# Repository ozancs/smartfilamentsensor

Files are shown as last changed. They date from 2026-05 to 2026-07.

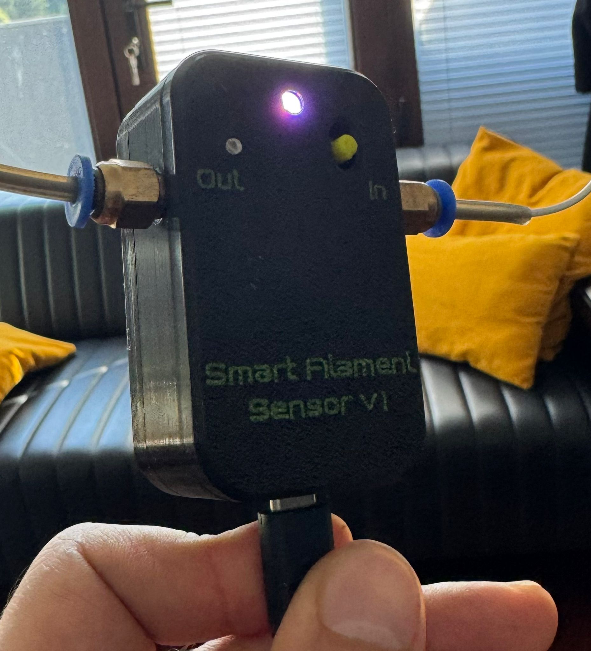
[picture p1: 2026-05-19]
photos/final.jpeg

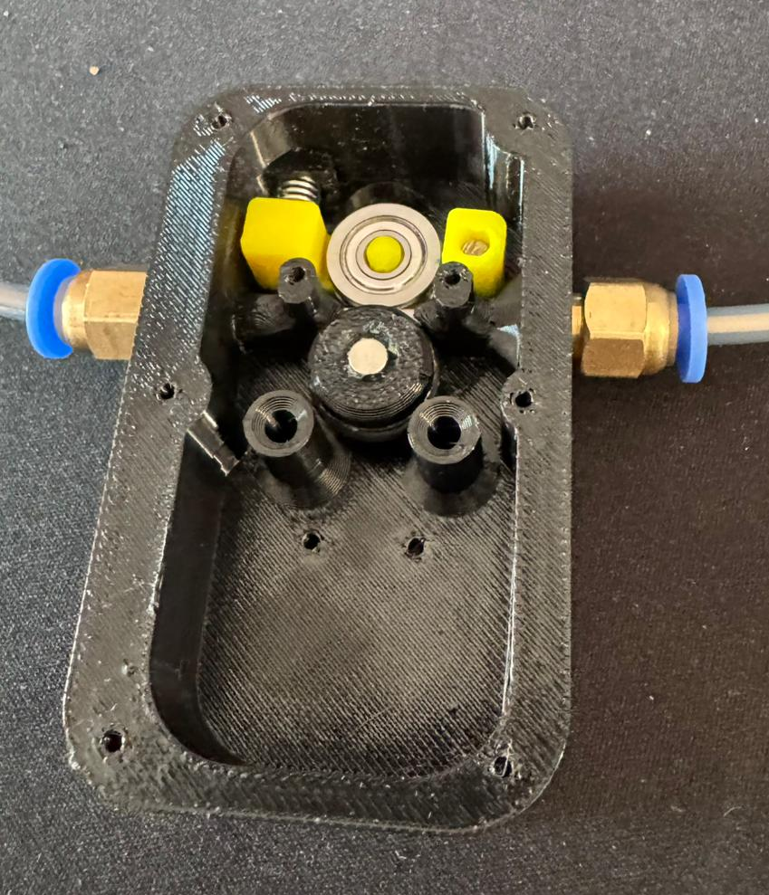
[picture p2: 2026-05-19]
photos/inside.png

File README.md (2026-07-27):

# Smart Filament Sensor

High-precision filament motion sensor for 3D printers. Uses an **ESP32-C3** and **AS5600** magnetic encoder to detect clogs, runouts, and slippage in real-time with native **Klipper** integration.

> **Build video coming soon** — in the meantime, follow the **[Installation Guide](INSTALLATION_GUIDE.md)** and use the [interactive CAD model](https://a360.co/4fwGLLL) for reference.

---

## Features

- **Sub-mm accuracy** — AS5600 contactless encoder (4096 steps/rev), no drift
- **Drag-immune clog detection** — averages over 200mm of *extrusion distance*, not seconds, so bowden drag cannot fake a clog (see [How It Works](#how-it-works))
- **Self-checking calibration** — measures encoder-vs-extruder gain live; if it drifts, the module warns instead of pausing your print for a calibration fault
- **Auto-detect serial port** — no need to manually set `/dev/ttyACM0`, finds ESP32 automatically
- **Underextrusion tracking** — rolling average exposed to Moonraker/Mainsail/Fluidd dashboards
- **Magnet health monitoring** — uses the AS5600's own MH/ML status bits, warns on weak, **too strong**, or missing magnet
- **Sensor watchdog** — detects USB disconnection, warns user, blocks commands when offline
- **Auto-reconnect** — recovers from USB dropouts on its own, no `FIRMWARE_RESTART` needed
- **No false pauses on dropout** — a disconnect means "no data", never "no filament"; detection state resyncs instead of tripping a clog
- **Homing awareness** — pauses detection during homing to prevent false triggers
- **One-command calibration** — `SFS_AUTO_CALIBRATE LENGTH=100`, heats, extrudes, saves
- **Built-in diagnostics** — `SFS_DIAG` dumps every AS5600 register for troubleshooting
- **Status LED** — WS2812B breathing/pulse animations (idle, moving, calibrating)
- **Windows console app** — portable .exe for calibration, live measurement, settings, firmware flashing

---

## Bill of Materials

| Component | Qty | Notes |
|---|---|---|
| ESP32-C3 Super Mini | 1 | Main MCU |
| AS5600 Encoder Module | 1 | With diametrical magnet |
| WS2812B NeoPixel 5050 | 1 | Status LED |
| Grooved Bearing (U604ZZ) | 2 | OD 13mm, ID 4mm |
| Dowel Pin 3mm x 15mm | 1 | Bearing axle |
| O-Ring (~11mm OD) | 1 | Filament grip |
| PC4-M6 Fitting | 2 | Bowden tube entry/exit |
| Compression Spring | 1 | Pen-style, cut to length |
| M3 Screw (M3x8-M3x10) | 1 | |
| M2 Self-Tapping Screw | 2 | AS5600 + ESP32 mount |

Full BOM: [`3d_print_files_and_bom/bom.html`](3d_print_files_and_bom/bom.html)

---

## 3D Printed Parts

Files in [`3d_print_files_and_bom/`](3d_print_files_and_bom/) (print-ready 3MF):

- `SmartFilament_Body_w_Text.3mf` / `SmartFilament_Body_w-out_Text.3mf`
- `BackCover.3mf` / `MagnetHolder.3mf` / `Spring_Arm.3mf`

**[Interactive CAD Model (Fusion 360)](https://a360.co/3QY3KFT)**

---

## Firmware

### Quick Flash (Windows)
1. Download `Smart Filament Sensor Console v2.1.exe`
2. Connect ESP32 via USB → open app → **Firmware** tab → **Flash**

### Build from Source (Arduino IDE)
1. Board: **ESP32C3 Dev Module** (Arduino ESP32 core)
2. Libraries: `AS5600`, `FastLED`
3. Tools → **USB CDC On Boot: Enabled**
4. Open `smart_filament_sensor.ino` → Upload

---

## Klipper Integration

ESP32 only measures filament movement. All clog detection logic runs inside Klipper.

### Setup (with auto-update)

```bash
cd ~
git clone https://github.com/ozancs/smartfilamentsensor.git
~/smartfilamentsensor/install.sh
```

Add to `moonraker.conf` for automatic updates:
```ini
[update_manager smart_filament_sensor]
type: git_repo
path: ~/smartfilamentsensor
origin: https://github.com/ozancs/smartfilamentsensor.git
install_script: install.sh
primary_branch: main
managed_services: klipper
```

**Manual install:** Upload `smart_filament_sensor.py` via Mainsail/Fluidd, then SSH and
`mv ~/printer_data/config/smart_filament_sensor.py ~/klipper/klippy/extras/`

Use `mv`, not `cp` — a leftover copy in the config folder shows up in the
Mainsail/Fluidd file list as if it were a config file, and editing that copy
silently does nothing because Klipper loads the one in `klippy/extras/`.

### printer.cfg

```ini
[smart_filament_sensor sfs]
serial: auto                      # auto-detects ESP32 (or use /dev/serial/by-id/...)
baud: 115200
detection_length: 7.0             # mm of extrusion between each encoder read
detection_window: 200.0           # mm of extrusion averaged per clog decision
underextrusion_max_rate: 0.5      # 0.0-1.0, trip if actual < 50% of expected
min_window_samples: 8             # reads required before any decision is made
encoder_scale: 1.0                # multiplies encoder mm (steady bias correction)
gain_tolerance: 0.25              # |gain-1| above this disarms detection
pause_on_runout: True
runout_gcode: PAUSE
health_check_interval: 30.0       # seconds between health checks
```

**A fixed `serial:` path is strongly recommended over `auto`.** With `auto`,
port probing writes `PING` to candidate ports; if one of them is a Klipper MCU
this can crash the printer. Find yours with `ls /dev/serial/by-id/`.

<details>
<summary><b>Upgrading from v2.x — what changed</b></summary>

`underextrusion_period` is gone. It used to set the averaging window in
*seconds*; the window is now set in *millimetres of extrusion* via
`detection_window`. Old configs still load (the value is reused as a
sample-staleness timeout), but you should replace it.

If you previously loosened `underextrusion_max_rate` to stop false pauses,
put it back to `0.5` — the distance window removes the reason you raised it.
</details>

### GCode Commands

**Detection:**
| Command | Description |
|---|---|
| `SFS_STATUS` | Sensor state, magnet health, encoder gain, window fill, armed/not |
| `SFS_ENABLE` / `SFS_DISABLE` | Toggle clog detection |
| `SFS_RESET` | Re-sync position, restart gain measurement |
| `SFS_DIAG` | Dump firmware version, calibration factor + all AS5600 registers (needs firmware >= 2.4.0) |
| `SFS_SUSPEND` / `SFS_RESUME` | Silence the module during probing (nestable) |

**Calibration:**
| Command | Description |
|---|---|
| `SFS_AUTO_CALIBRATE TEMP=240 LENGTH=100` | One-command: heat, extrude, save |
| `SFS_CALIBRATE LENGTH=100` | Manual calibration start |
| `SFS_CALIBRATE_APPLY` | Save calibration immediately |
| `SFS_CALIBRATE_STOP` | Cancel calibration |

**ESP32 Settings:**
| Command | Description |
|---|---|
| `SFS_SET SENS=5 NOISE=3` | Sensitivity + noise filter |
| `SFS_SET BRIGHT=80` | LED brightness (1-255) |
| `SFS_SET DIR=-1` | Reverse encoder direction |
| `SFS_SET CAL=12.5` | Manual calibration factor (deg/mm) |

### Calibration

```gcode
; Automatic (recommended) — heats, extrudes, saves:
SFS_AUTO_CALIBRATE TEMP=240 LENGTH=100 SPEED=100

; Manual — you control the extrusion:
SFS_CALIBRATE LENGTH=100
G1 E100 F100
SFS_CALIBRATE_APPLY
```

Use **100mm, not 50mm**. The wheel travels ~30mm of filament per revolution,
so a short extrude samples only part of one turn and any per-revolution error
folds straight into the result.

### Verifying calibration

Calibrating is not the same as being calibrated. Run a normal print, then:

```gcode
SFS_STATUS
```

Look at **`encoder_gain`** — the long-run ratio of measured to commanded
extrusion. It should settle near `1.000`.

| `encoder_gain` | Meaning |
|---|---|
| ~1.00 | Correct. Clog detection is armed. |
| < 0.90 | The wheel is turning less than the filament moves. Detection **disarms itself** and warns. |
| > 1.10 | Reading too much movement — check magnet placement. |
| negative | The encoder counts backwards. Flip it with `SFS_SET DIR=-1` (or `DIR=1`), then `SFS_RESET`. Usually means the magnet was reinstalled the other way up. |

A low gain that *survives recalibration* is mechanical, not a config problem:
the O-ring is slipping on the filament. Check spring pressure, O-ring
condition, and that the filament path through the sensor is straight.

Full guide: [`klipper_guide/KLIPPER_GUIDE.txt`](klipper_guide/KLIPPER_GUIDE.txt)

---

## Console App (Windows)

Portable `.exe` — no installation required.

- **Dashboard** — calibration wizard, live mm readout, sensor settings
- **Serial Monitor** — raw terminal with quick-action buttons for all commands
- **Firmware** — one-click ESP32 flash with bundled esptool
- **Klipper Guide** — config snippets and full Python module

---

## How It Works

```
Every 7mm of extrusion, Klipper asks the ESP32 how much filament actually moved.
Those readings are accumulated until they cover 200mm of commanded extrusion,
and only then is a clog decision made.

  read  1:  7.0mm commanded  →  -4.8mm measured     (toolhead pulled filament back)
  read  2:  7.0mm commanded  →  15.2mm measured     (and let it go again)
  read  3:  7.0mm commanded  →   6.9mm measured
  ...
  window full: 200mm commanded → 197mm measured     → 1.5% deficit ✓ keep printing
  window full: 200mm commanded →  22mm measured     → 89% deficit  ✗ PAUSE
```

### Why the window is measured in millimetres, not seconds

The sensor is frame-mounted and reaches the toolhead through a bowden tube, so
the filament between them is not rigidly coupled. As the toolhead moves, the
path length changes and filament is dragged back and forth through the encoder;
buckling inside the tube stores and releases even more. On real prints,
individual 7mm reads came back anywhere from **-13.8mm to +17.2mm** — with
retraction set to only 0.8mm.

This drag is bounded in millimetres and averages to zero over distance. A real
clog, by contrast, reads ~100% deficit no matter how long you look. So the
longer the window *in millimetres*, the better drag separates from clogs:

| Averaging window | Worst false reading from drag alone |
|---|---|
| 25 mm | 260 % |
| 50 mm | 106 % |
| 100 mm | 88 % |
| 150 mm | 58 % |
| **200 mm** | **41 %** |
| 300 mm | 26 % |

At 200mm the 50% threshold has real margin, and a total clog is still caught
after ~115mm of extrusion (roughly 25 seconds at typical flow).

A time-based window cannot do this. Detection reads arrive about every 2
seconds on a real print, so a 5-second average held a median of **three**
samples — not enough to average anything. That is what produced false clogs on
first layers and solid infill, where long sweeping moves drag the filament
hardest.

### Detection is disarmed when it cannot be trusted

A steady calibration error is indistinguishable from a partial clog inside any
single window. So instead of guessing, the module tracks the long-run
encoder-to-extruder gain and refuses to decide when that gain is off:

```
clog detection NOT ARMED.
  Encoder reads 63% of commanded extrusion (should be ~100%).
  This is a calibration problem, not a clog — the module will not pause
  the print for it.
```

---

## Magnet Health

`SFS_STATUS` reports the encoder's AGC (Automatic Gain Control) value. Per the
AS5600 datasheet the ideal AGC is the **middle** of its range — and the range
depends on supply voltage:

| Supply | AGC range | Ideal |
|---|---|---|
| 3.3V (ESP32-C3) | 0-128 | ~64 |
| 5V | 0-255 | ~128 |

AGC pinned at **0** means the magnet is too close (too strong); pinned at the
**top** means it is too far. Both degrade angle accuracy. Adjust the air gap
between the AS5600 board and the magnet — 1-2mm is the target — until AGC
lands near the middle.

Run `SFS_DIAG` to see AGC, magnitude, and every configuration register at once.

---

## LED Status

| LED | Meaning |
|---|---|
| White breathing | Idle |
| Blue pulsing | Filament moving |
| Solid green | Measure mode |
| Solid yellow | Calibration mode |
| LED off | Deep idle (5min+) |

---

## Project Structure

```
smartfilamentsensor/
├── klipper_guide/
│   ├── smart_filament_sensor.py   # Klipper module
│   └── KLIPPER_GUIDE.txt
├── 3d_print_files_and_bom/        # 3MF + BOM
├── photos/
├── firmware/                       # Pre-built .bin files
├── smart_filament_sensor.ino       # ESP32 firmware source
├── INSTALLATION_GUIDE.md
└── README.md
```

---

## License

Open-source. Free to use, modify, and distribute.

Created by **Ozan Sahin**

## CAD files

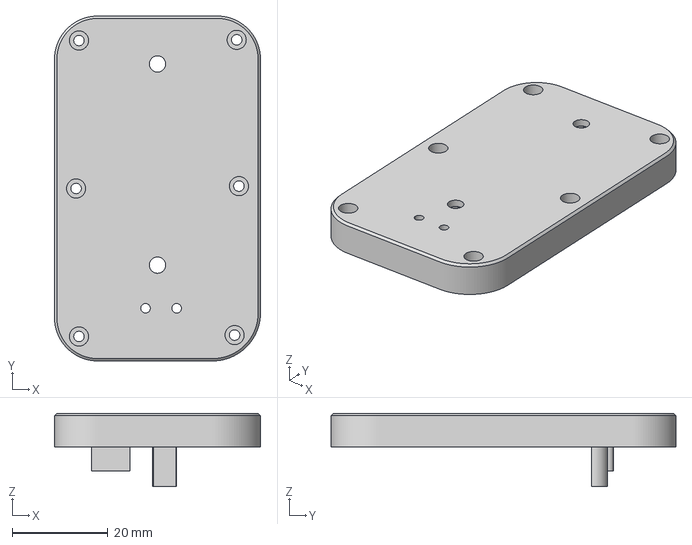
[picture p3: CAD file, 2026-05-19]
3d_print_files_and_bom/BackCover.3mf
43.0 x 72.0 x 15.3 mm

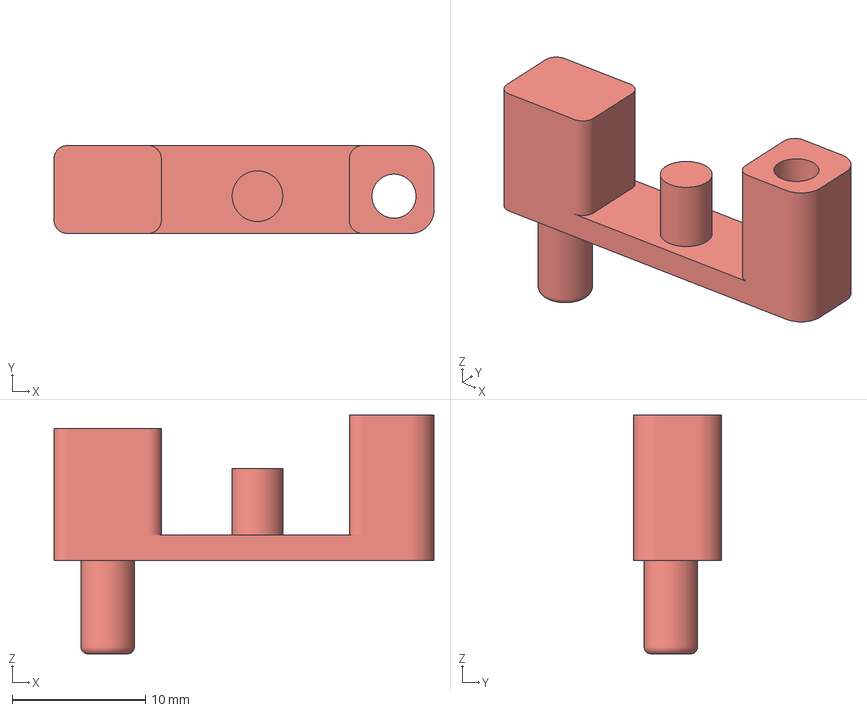
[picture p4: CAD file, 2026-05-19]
3d_print_files_and_bom/Spring_Arm.3mf
28.5 x 6.60 x 17.9 mm

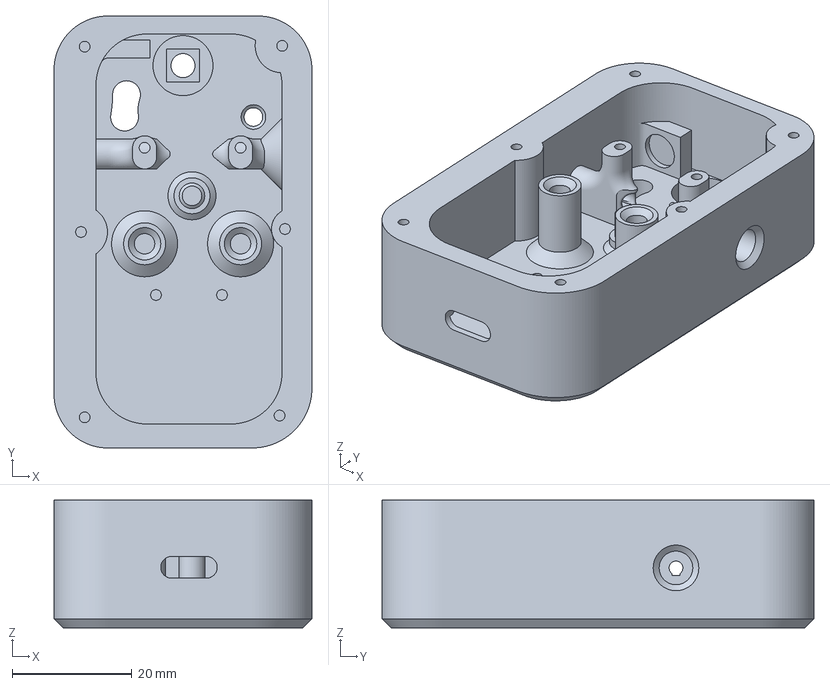
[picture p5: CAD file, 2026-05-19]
3d_print_files_and_bom/SmartFilament_Body_w-out_Text.3mf
43.0 x 72.0 x 21.3 mm

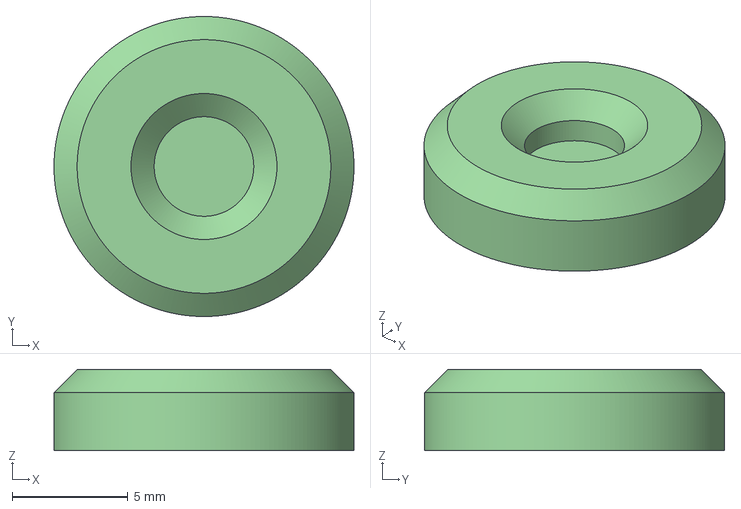
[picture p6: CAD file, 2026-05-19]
3d_print_files_and_bom/MagnetHolder.3mf
12.9 x 12.9 x 3.50 mm

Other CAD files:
3d_print_files_and_bom/SmartFilament_Body_w_Text.3mf

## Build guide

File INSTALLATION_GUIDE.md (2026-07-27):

# Smart Filament Sensor — Installation Guide

Step-by-step assembly, wiring, and first-run instructions. No special tools required beyond a soldering iron and basic screwdrivers.

> **Tip:** Open the [interactive CAD model](https://a360.co/4fwGLLL) side-by-side while building — you can rotate and measure every part.

---

## 1. Prepare the Bearing & Magnet Assembly

### 1.1 O-Ring on Bearing

Take one of the two **U604ZZ grooved bearings** (OD 13mm, ID 4mm) and stretch the **O-Ring (~11mm OD)** over its groove. The O-ring sits in the bearing's channel and provides grip so the filament drives the bearing as it passes through.

### 1.2 Magnet Holder

Take the **MagnetHolder** (3D printed part: `MagnetHolder.3mf`) and attach it to the top of this bearing using small strips of **double-sided tape on the edges only**.

> **Important:** Only tape the outer edges of the magnet holder to the bearing. The center must spin freely — this is how the encoder tracks rotation.

### 1.3 Magnet

Press the **diametrical magnet** (included with the AS5600 module) into the pocket on top of the magnet holder. A drop of glue or friction fit will keep it in place. Make sure it is centered and sits flush.

---

## 2. Main Body Assembly

### 2.1 Bearing into Body

Place the bearing + magnet holder assembly into the **SmartFilament Body** (3D printed part: `SmartFilament_Body_w_Text.3mf` or `SmartFilament_Body_w-out_Text.3mf`). It should drop into its seat with minimal play — slight movement is fine, but it must not fall out when tilted.

### 2.2 Spring Arm & Second Bearing

Take the **Spring Arm** (3D printed part: `Spring_Arm.3mf`) and press the second **U604ZZ grooved bearing** into the center pocket. This should be a snug fit. If the bearing is loose due to print tolerances, wrap a thin strip of tape around the bearing's outer edge and press it in until fully seated.

### 2.3 Dowel Pin & Spring Arm

Insert the **3mm x 15mm dowel pin** (smooth hardened steel) into the pivot hole on the main body. Then slide the spring arm (with bearing installed) onto the dowel pin.

### 2.4 Spring

Place the **compression spring** (pen-style) into its slot between the body and the spring arm. The spring arm should press the second bearing against the first, sandwiching the filament path.

> **Feel check:** Push the spring arm by hand. It should offer firm but smooth resistance — not so stiff that filament can't push through, not so loose that it won't grip. If the spring is too strong, trim it shorter with wire cutters. This is a feel-based adjustment, there's no exact spec.

### 2.5 PTFE Fittings

Thread the two **PC4-M6 pneumatic fittings** into the entry and exit holes on the main body. They should screw in smoothly by hand. If the threads are tight from print tolerances, wrap a tiny bit of tape around the threads for a tighter seal.

---

## 3. Wiring

### 3.1 Pin Reference

**AS5600 Encoder → ESP32-C3:**

| AS5600 Pin | ESP32-C3 Pin | Notes |
|---|---|---|
| VCC | 3.3V | **3.3V only** — do not use 5V |
| GND | GND | |
| SDA | GPIO 4 | I2C data |
| SCL | GPIO 5 | I2C clock |

**WS2812B NeoPixel LED → ESP32-C3** *(optional)*:

| LED Pin | ESP32-C3 Pin | Notes |
|---|---|---|
| VCC | 5V (VBUS) | Needs 5V for full brightness |
| GND | GND | |
| DIN | GPIO 2 | Data in |

> **Note:** The status LED is optional. If you don't want it, skip all LED wiring. The sensor works perfectly without it.

### 3.2 Soldering

Cut wires to appropriate lengths — leave enough slack so nothing is under tension when the enclosure is closed, but not so long that wires bunch up and interfere with the moving spring arm.

Solder all connections according to the pin table above. Double-check polarity on the LED (VCC/GND) and the AS5600 (3.3V, not 5V).

---

## 4. Electronics Installation

### 4.1 Status LED

Press the **WS2812B NeoPixel** into its square pocket on the main body. It's a tight fit by design — push it in firmly but carefully to avoid damaging the LED or its solder joints. **Pay attention to orientation** — the square LED should align with the square pocket. Check that the DIN wire faces the correct direction before pressing in.

### 4.2 ESP32-C3

Stick a small piece of **double-sided foam tape** to the back of the ESP32-C3 Super Mini. Place it into its slot in the main body. The foam tape keeps it in place and provides insulation.

Secure the ESP32 with **2x M2 self-tapping screws** through the screw holes at the rear of the ESP32 slot. These prevent the board from sliding backward — the foam tape alone isn't enough.

### 4.3 AS5600 Encoder

The AS5600 module mounts directly above the magnet. The main body has **2 wide holes for M3 heat-set inserts** — press the inserts in with a soldering iron, then secure the AS5600 from above with **2x M3 screws**.

On the opposite side, use **2x M2 self-tapping screws** through the remaining mounting holes. The AS5600 is held by **4 screws total** (2x M3 + 2x M2) for a solid, vibration-free mount.

> **Critical:** The AS5600 chip must sit centered directly above the magnet, with a small air gap (1-2mm). If it's too far, the sensor won't detect the magnet. Too close and it might touch the spinning magnet holder.

---

## 5. Back Cover & Mounting

### 5.1 M3 Nuts

The **BackCover** (3D printed part: `BackCover.3mf`) has **2 recessed pockets** on its inner face for M3 nuts. Press a nut into each pocket — these are for mounting the sensor to your printer frame later.

### 5.2 Close the Enclosure

Route all wires so they don't get pinched or interfere with the spring arm mechanism. Then attach the back cover to the main body using **6x M2 self-tapping screws**.

> **Cable check:** Before fully tightening, gently push the spring arm to make sure no wires are caught in the mechanism.

### 5.3 Printer Mounting

Use the 2x M3 bolt holes (through the back cover nuts) to mount the sensor to your printer's frame, bowden tube path, or a custom bracket. Mounting options and brackets may be added in the future.

---

## 6. Firmware & First Run

### Option A: Windows Console App (Recommended)

1. Download **Smart Filament Sensor Console.exe** from [Releases](../../releases)
2. Connect the ESP32 to your PC via USB
3. The app auto-detects the sensor — click **Connect**
4. Go to **Firmware** tab → **Start Firmware Flash**
5. After flashing, go to **Dashboard** → run calibration

### Option B: Arduino IDE

1. Install **Arduino ESP32 core** (board: ESP32C3 Dev Module)
2. Install libraries: `AS5600`, `FastLED`
3. In **Tools** menu: set **USB CDC On Boot → Enabled**
4. Open `smart_filament_sensor.ino` and upload
5. Open Serial Monitor at 115200 baud, type `HELP`

### First Calibration

The sensor ships with a default calibration factor (12.5 deg/mm) that will be inaccurate for your specific build. **You must calibrate before use.**

**Using the Console App:**
1. Go to Dashboard → Calibration card
2. Set target to 50mm, click **Start Calibration**
3. Push exactly 50mm of filament through the sensor by hand (use a ruler)
4. Wait 5 seconds — calibration auto-saves

**Using Klipper:**
```gcode
SFS_CALIBRATE LENGTH=50
G1 E50 F100
SFS_CALIBRATE_APPLY
```

**Using Serial Terminal:**
```
START 50
(push 50mm of filament, wait 5 seconds)
```

After calibration, verify with the **Measure** mode — push a known length and check that the reading matches.

---

## 7. Klipper Setup

See the full [Klipper Integration Guide](klipper_guide/KLIPPER_GUIDE.txt) for detailed instructions.

Quick start:
```bash
cp klipper_guide/smart_filament_sensor.py ~/klipper/klippy/extras/
sudo systemctl restart klipper
```

`cp` is correct here — this copies out of the cloned repo, which must keep its
own copy for `git pull` / update_manager to work. If you instead uploaded the
file through Mainsail/Fluidd, use `mv` so no stray copy is left in your config
folder.

Add to `printer.cfg`:
```ini
[smart_filament_sensor my_sensor]
serial: auto                    # or a fixed /dev/serial/by-id/... path
baud: 115200
detection_length: 7.0           # mm of extrusion per encoder read
detection_window: 200.0         # mm of extrusion averaged per clog decision
underextrusion_max_rate: 0.5    # deficit that counts as a clog
min_window_samples: 8           # reads required before deciding
encoder_scale: 1.0              # encoder mm multiplier (bias correction)
gain_tolerance: 0.25            # |gain-1| above this disarms detection
pause_on_runout: True
runout_gcode: PAUSE
health_check_interval: 30.0     # seconds between magnet health checks
```

---

## Troubleshooting

| Problem | Solution |
|---|---|
| Sensor not detected on USB | Make sure **USB CDC On Boot** is enabled in Arduino IDE. Reflash if needed. |
| No magnet detected (warning on boot) | Check magnet is centered in the holder, AS5600 air gap is 1-2mm. |
| Magnet too strong / too weak | Adjust the AS5600-to-magnet air gap. Run `SFS_DIAG`: ideal AGC is the MIDDLE of its range (~64 at 3.3V, ~128 at 5V). AGC pinned at 0 means the magnet is too close. |
| Inconsistent readings | Re-calibrate with a longer distance (100mm). Check O-ring grip and bearing spin. |
| Spring too stiff | Trim the compression spring shorter. |
| PTFE fittings loose | Wrap thread tape around the fitting threads. |
| Wires caught in mechanism | Re-route wires away from the spring arm, re-close back cover. |
| "Sensor disconnected" warning in Klipper | Check USB cable, try a different port. Sensor auto-reconnects when restored. |
| False clog during homing | Update to v2.2 — homing awareness automatically pauses detection during homing moves. |

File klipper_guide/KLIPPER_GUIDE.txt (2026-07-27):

===============================================================================
  SMART FILAMENT SENSOR (SFS) — Klipper Integration Guide v3.1.2
===============================================================================

  ESP32 + AS5600 encoder based filament sensor with native Klipper module.
  ESP32 only measures filament movement. All underextrusion detection
  and pause logic runs inside Klipper.

  v3 CHANGE: clog decisions are averaged over DISTANCE (mm of commanded
  extrusion), not over seconds. The sensor is frame-mounted and reaches the
  toolhead through a bowden tube, so toolhead motion drags filament back and
  forth through the encoder -- single reads swing from -13.8mm to +17.2mm
  against a 7mm command. That drag averages out over distance; a clog does
  not. See "DETECTION TUNING" below.

===============================================================================
  1. INSTALLATION
===============================================================================

  Option A — Git install (recommended, enables auto-update):

    cd ~
    git clone https://github.com/ozancs/smartfilamentsensor.git
    ~/smartfilamentsensor/install.sh

  Add to moonraker.conf for automatic updates:

    [update_manager smart_filament_sensor]
    type: git_repo
    path: ~/smartfilamentsensor
    origin: https://github.com/ozancs/smartfilamentsensor.git
    install_script: install.sh
    primary_branch: main
    managed_services: klipper

  Option B — Manual install:

    1. Upload smart_filament_sensor.py via Mainsail/Fluidd (Machine tab)
    2. SSH: mv ~/printer_data/config/smart_filament_sensor.py ~/klipper/klippy/extras/

       mv, not cp. A leftover copy in the config folder appears in the
       Mainsail/Fluidd file list as though it were a config file, and
       editing that copy does nothing -- Klipper loads klippy/extras/.

  Then add to printer.cfg:

    [smart_filament_sensor sfs]
    serial: auto                    # fixed by-id path strongly recommended
    baud: 115200
    detection_length: 7.0           # mm of extrusion per encoder read
    detection_window: 200.0         # mm of extrusion averaged per decision
    underextrusion_max_rate: 0.5    # deficit that counts as a clog
    min_window_samples: 8           # reads required before deciding
    encoder_scale: 1.0              # encoder mm multiplier (bias correction)
    gain_tolerance: 0.25            # |gain-1| above this disarms detection
    pause_on_runout: True
    runout_gcode: PAUSE
    health_check_interval: 30.0

  UPGRADING FROM v2.x:
    underextrusion_period is no longer the averaging window. Replace it with
    detection_window (millimetres). Old configs still load -- the value is
    reused as a sample-staleness timeout -- but it no longer does what its
    name says.

  Step 4 — Restart Klipper:

    sudo systemctl restart klipper

===============================================================================
  2. CONFIG PARAMETERS
===============================================================================

  serial                 ESP32 serial port. "auto" = auto-detect via
                         PING/PONG handshake (recommended). Or use a
                         stable path like /dev/serial/by-id/...
  baud                   Baud rate, must match ESP32 firmware (default: 115200)
  detection_length       mm of extrusion between each check (default: 7.0)
  pause_on_runout        automatically pause on detection (default: True)
  runout_gcode           gcode to run on clog/runout (default: PAUSE)
  underextrusion_max_rate  underextrusion ratio threshold (0.0-1.0).
                         0.5 = pause if actual extrusion < 50% of expected.
                         (default: 0.5)
  underextrusion_period  how many seconds underextrusion must persist
                         before triggering a pause (default: 5.0)
  health_check_interval  seconds between magnet health checks (default: 30.0)

  How detection works:
    - Klipper extrudes 7mm, ESP32 encoder measures actual movement
    - Rolling underextrusion rate is calculated over recent readings
    - If rate exceeds underextrusion_max_rate, a timer starts
    - If it stays bad for underextrusion_period seconds -> PAUSE
    - If it recovers before the timer expires -> timer resets, no pause
    - Single bad readings are NEVER enough to pause a print

===============================================================================
  3. GCODE COMMANDS
===============================================================================

  -- Clog Detection --

  SFS_STATUS
      Show current sensor state: connection, magnet health,
      underextrusion rate, timer status, detection config.

  SFS_ENABLE
      Enable clog detection. Resets odometer and re-syncs extruder.

  SFS_DISABLE
      Disable clog detection without disconnecting the sensor.

  SFS_RESET
      Re-sync Klipper extruder position with ESP32 odometer.
      Clears underextrusion history and resets timer.

  -- Calibration --

  SFS_AUTO_CALIBRATE [TEMP=240] [LENGTH=50] [SPEED=100]
      One-command calibration. Heats hotend to TEMP, extrudes
      LENGTH mm at SPEED (mm/min), auto-saves result.
      No manual steps needed — just run and wait.

      TEMP    Hotend temperature in C (default: 200)
      LENGTH  Filament to extrude in mm (default: 50)
      SPEED   Extrusion speed in mm/min (default: 100)

  SFS_CALIBRATE [LENGTH=10]
      Manual calibration start. You control the extrusion.
      After filament stops, waits 5s then auto-saves.

  SFS_CALIBRATE_APPLY
      Force-save calibration immediately (skip 5s wait).

  SFS_CALIBRATE_STOP
      Cancel active calibration without saving.

  -- ESP32 Settings --

  SFS_SET [SENS=<1-50>] [NOISE=<1-20>] [BRIGHT=<1-255>] [DIR=<1/-1>] [CAL=<float>]

      SENS    Movement sensitivity (encoder steps). Higher = less sensitive.
      NOISE   Noise filter deadband. Higher = more filtering.
      BRIGHT  Status LED brightness.
      DIR     Encoder direction. Set -1 if sensor reads backwards.
      CAL     Calibration factor (deg/mm). Normally set by SFS_CALIBRATE.

  Examples:
      SFS_SET BRIGHT=10
      SFS_SET SENS=3 NOISE=2
      SFS_SET BRIGHT=80 DIR=-1

===============================================================================
  4. CALIBRATION WALKTHROUGH
===============================================================================

  Automatic (recommended):

    SFS_AUTO_CALIBRATE TEMP=240 LENGTH=50 SPEED=100

    That's it! The sensor heats the hotend, extrudes 50mm, and saves.

  Manual (if you need more control):

    1.  SFS_CALIBRATE LENGTH=50       ; start calibration
    2.  G1 E50 F100                   ; extrude 50mm slowly
    3.  ; Wait 5 seconds...           ; ESP32 auto-saves
        ; or: SFS_CALIBRATE_APPLY     ; save immediately

  Output:
    >>> CALIBRATION SUCCESS!
    >>> Measured: 49.82 mm | Target: 50.0 mm
    >>> New Cal Factor: 12.3456 deg/mm (saved)

  If the result is unusual (< 3 or > 50 deg/mm), a warning appears.
  Check magnet position, encoder direction, or re-calibrate.

  Tips:
    - Longer calibration (50-100mm) = better accuracy
    - Extrude slowly (F60-F100) for consistent results
    - Cal factor is saved to ESP32 flash, survives power off

===============================================================================
  5. OPTIONAL PAUSE / RESUME MACROS
===============================================================================

  Note: Mainsail.cfg already includes PAUSE/RESUME macros.
  Only add these if you DON'T have them:

    [gcode_macro PAUSE]
    rename_existing: BASE_PAUSE
    gcode:
      SAVE_GCODE_STATE NAME=PAUSE_state
      BASE_PAUSE
      G91
      G1 Z10 F600
      G90
      G1 X10 Y10 F6000

    [gcode_macro RESUME]
    rename_existing: BASE_RESUME
    gcode:
      RESTORE_GCODE_STATE NAME=PAUSE_state MOVE=1 MOVE_SPEED=80
      BASE_RESUME

===============================================================================
  6. ADVANCED FEATURES (v2.5)
===============================================================================

  -- Time-Based Underextrusion Detection --

  Instead of pausing on every single bad reading, the module uses
  a time-based approach (inspired by Roadrunner filament sensor):

    1. Rolling underextrusion rate is calculated from recent readings
    2. If rate > underextrusion_max_rate -> timer starts
    3. If rate stays bad for underextrusion_period seconds -> PAUSE
    4. If rate recovers -> timer resets, print continues

  This means:
    - A momentary hiccup never pauses your print
    - A real clog is detected within seconds
    - Gradual nozzle clogs are caught by sustained underextrusion

  SFS_STATUS shows the timer:
    underextrusion_timer=idle      -> all good
    underextrusion_timer=2.3s      -> alarm active, counting

  -- Auto-Detect Serial Port --

  Set serial: auto in printer.cfg. The module will:
    1. Scan /dev/serial/by-id/ for ESP32 devices
    2. Send PING and verify PONG response
    3. Fall back to /dev/ttyACM* and /dev/ttyUSB* with verification
  This prevents grabbing CAN adapters or EBB boards by mistake.

  -- Retraction Filter --

  Retraction moves (negative E) are properly handled:
    - Normal retraction (up to 20mm): tracked but not reset
    - G92 E0 or slicer E-reset (>20mm jump): encoder re-synced
  Retract + unretract cancel out in the encoder, no false triggers.

  -- Magnet Health Monitoring --

  Every health_check_interval seconds, the ESP32's magnet is checked:
    ok          Magnet detected, AGC in healthy range
    too_weak    Magnet signal weak (move closer)
    no_magnet   No magnet detected (critical)

  -- Sensor Connection Watchdog --

  If no response is received within health_check_interval + 10s,
  the sensor is marked disconnected. All commands check connection
  before executing — no silent failures.

  If the serial reader thread crashes, it's detected and reported.

  -- Homing Awareness --

  Detection is paused during homing moves. Odometer re-syncs after.

  -- Moonraker / Dashboard Data --

  get_status() exposes:
    enabled               bool    detection on/off
    sensor_connected      bool    ESP32 communication status
    magnet_state          string  ok / too_weak / no_magnet
    magnet_agc            int     raw AGC value (0-255)
    underextrusion_rate   float   0.0 (perfect) to 1.0 (total clog)
    underextrusion_max_rate float configured threshold
    underextrusion_alarming bool  timer is running
    detection_length      float   mm between checks
    is_printing           bool    print state
    is_homing             bool    homing in progress

===============================================================================
  7. TROUBLESHOOTING
===============================================================================

  "Sensor not found" / auto-detect failed
    - Check ESP32 is connected: ls /dev/ttyACM* /dev/ttyUSB*
    - Make sure no other process holds the port (screen, minicom)
    - Add user to dialout: sudo usermod -aG dialout $USER
    - Try setting serial to explicit path instead of auto

  "Sensor disconnected" warning
    - Check USB cable
    - Try a different USB port (avoid hubs)
    - Run FIRMWARE_RESTART to reconnect

  "Magnet not detected"
    - Check magnet is centered in the holder
    - Verify AS5600 air gap is 1-2mm
    - Check AGC in SFS_STATUS (healthy: 40-200)

  False pauses / too sensitive
    - Increase underextrusion_max_rate (e.g. 0.7 = only pause if <30% flow)
    - Increase underextrusion_period (e.g. 10.0 = must persist 10 seconds)
    - Re-calibrate: SFS_CALIBRATE LENGTH=100

  Never detects clogs
    - Decrease underextrusion_max_rate (e.g. 0.3)
    - Decrease underextrusion_period (e.g. 3.0)
    - Check SFS_STATUS — is detection enabled?
    - Verify sensor is connected and magnet OK

  Encoder reads wrong direction
    - SFS_SET DIR=-1

  "ERROR - sensor not connected" on commands
    - Sensor is offline, commands are blocked for safety
    - Plug in sensor and run FIRMWARE_RESTART

===============================================================================

===============================================================================
  DETECTION TUNING
===============================================================================

  detection_window (mm of commanded extrusion averaged per decision)

    Bowden drag is bounded in millimetres, so its relative contribution
    shrinks as the window grows. A clog reads ~100% deficit at any window
    size. Worst false reading produced by drag alone, measured on real logs:

        25 mm  -> 260 %        150 mm ->  58 %
        50 mm  -> 106 %        200 mm ->  41 %   <- default
       100 mm  ->  88 %        300 mm ->  26 %

    Larger  = safer against false pauses, slower to catch a real clog.
    Smaller = faster reaction, less margin.
    At 200mm a total clog trips after ~115mm of extrusion (~25s typical).

    If your sensor sits very close to the extruder with little tube between
    them, drag is smaller and you can lower this. If you still see false
    pauses, raise it before touching underextrusion_max_rate.

  min_window_samples

    Floor on how many reads must be in the window regardless of distance.
    Stops a decision being made from two or three readings.

  encoder_scale

    Multiplies every encoder reading. Only for a steady bias you have
    measured and cannot remove by calibrating the ESP32. Prefer fixing the
    calibration; this is an escape hatch, not a substitute.

  gain_tolerance

    The module continuously measures the long-run ratio of measured to
    commanded extrusion (SFS_STATUS -> encoder_gain). If |gain - 1| exceeds
    this, clog detection DISARMS and prints a warning instead of pausing.
    A steady gain error is indistinguishable from a partial clog inside a
    single window, so the module refuses to guess.

===============================================================================
  DIAGNOSING A LOW encoder_gain
===============================================================================

  Run SFS_STATUS after a print. encoder_gain should be near 1.000.

  If it is low (encoder reads less than the extruder commanded):

  0. Is encoder_gain NEGATIVE? The encoder is counting backwards -- flip it
     with SFS_SET DIR=-1 (or DIR=1), then SFS_RESET. This happens if the
     magnet or its holder is reinstalled the other way up. Calibration is
     unaffected: the firmware takes the absolute value, so only the sign is
     wrong.

  1. SFS_DIAG -- check the register dump.

     zpos / mpos / mang non-zero
         The ANGLE register is being scaled and clipped by the chip. The
         firmware uses rawAngle() so this no longer matters, but it means
         someone wrote those registers.

     agc at 0, or at the top of its range
         Magnet too strong / too weak. Ideal AGC is the MIDDLE of the range:
         ~64 at 3.3V (range 0-128), ~128 at 5V (range 0-255). Adjust the air
         gap to 1-2mm. Both extremes degrade angle accuracy.

  2. SFS_AUTO_CALIBRATE TEMP=<your temp> LENGTH=100
     Then run a print and check encoder_gain again.

  3. If the gain is STILL low after recalibrating, the problem is mechanical:
     the O-ring is slipping on the filament. Compare the stored deg/mm
     against the wheel geometry --

         deg_per_mm = 360 / (pi * effective_contact_diameter_mm)

     With the stock ~11mm O-ring that is about 10.4 deg/mm. A stored value
     far above that means the wheel is turning less than geometry says it
     should, i.e. it is slipping. Check spring pressure, O-ring wear, and
     that the filament runs straight through the sensor.

===============================================================================
  A NOTE ON serial: auto
===============================================================================

  Auto-detect opens candidate serial ports and writes PING to them. If one of
  those is a Klipper MCU, that write corrupts its protocol stream and takes
  the printer down ("Missed scheduling of next digital out event"), which also
  kills any CAN board bridged through it.

  The module already refuses to probe any port listed in an [mcu] section, but
  a fixed path is safer and costs nothing:

      ls /dev/serial/by-id/
      serial: /dev/serial/by-id/usb-Espressif_USB_JTAG_serial_debug_unit_XX...

  The by-id path is MAC-based and never changes.

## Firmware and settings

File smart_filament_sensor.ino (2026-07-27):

#include <Wire.h>
#include <AS5600.h>
#define FASTLED_INTERNAL       // Suppress FastLED pragma messages
#include <FastLED.h>
#include <Preferences.h>

#define SDA_PIN 4
#define SCL_PIN 5
#define NEO_PIN 2
#define NUM_LEDS 1
#define FW_VERSION "2.5.0"

Preferences prefs;
AS5600 as5600;
CRGB leds[NUM_LEDS];

// ── Settings (NVS persisted) ──
float degrees_per_mm;
int sensitivity;        // Runout: minimum steps to count as "filament moving"
int noise_threshold;    // Deadband: ignore encoder jitter below this
int direction_multiplier;
int led_brightness;     // 1-255

// ── Encoder State ──
uint16_t lastAngle = 0;
long long global_steps = 0; 
long long session_start_steps = 0;
long long odometer_reset_steps = 0;
float lastLoggedMm = -999.0; 

// ── Mode Flags ──
bool measure_active = false;
bool test_active = false;
float test_target = 10.0;

// ── Timing ──
unsigned long lastMoveTime = 0;
unsigned long lastMoveLedTime = 0;
const unsigned long TIMEOUT_MS = 5000;
const unsigned long DEEP_IDLE_TIMEOUT_MS = 300000; // 5 minutes (5 * 60 * 1000)

// ── LED Animation ──
CRGB currentColor = CRGB::Black;
CRGB targetColor = CRGB::Black;

// ── Distance Calculation ──
double calculateDistance(long long steps) {
    if (degrees_per_mm < 0.01f) return 0.0;
    double distance = ((double)steps * 360.0) / (4096.0 * (double)degrees_per_mm);
    return distance * (double)direction_multiplier;
}

// ── LED Animation Engine (FastLED, ultra-smooth) ──
//
// Rate-limited to LED_FPS. FastLED.show() disables interrupts while it
// bit-bangs the WS2812 line and then waits out the reset latch; calling it
// on every loop iteration spent most of the loop budget on an LED nobody can
// see change faster than ~60Hz, and stole time from encoder polling. The
// encoder is read every iteration regardless -- only the LED is throttled.
static unsigned long lastLedUpdate = 0;
const unsigned long LED_INTERVAL_MS = 1000 / 60;   // 60 FPS

void updateLed() {
    unsigned long now = millis();
    if (now - lastLedUpdate < LED_INTERVAL_MS) return;
    lastLedUpdate = now;
    
    if (test_active) {
        // CALIBRATION: Smooth fade to warm yellow
        targetColor = CRGB(255, 180, 0);
        nblend(currentColor, targetColor, 30);
        leds[0] = currentColor;
    } 
    else if (measure_active) {
        // MEASURE: Smooth fade to green
        targetColor = CRGB(0, 255, 0);
        nblend(currentColor, targetColor, 30);
        leds[0] = currentColor;
    }
    else if (now - lastMoveLedTime < 1500) {
        // MOVEMENT: Direct 16-bit blue pulse (no nblend lag)
        uint16_t pulse16 = beatsin16(100, 0, 65535);
        uint8_t pulse = pulse16 >> 8;
        currentColor = CRGB(0, 0, pulse);
        leds[0] = currentColor;
    }
    else if (now - lastMoveTime >= DEEP_IDLE_TIMEOUT_MS) {
        // DEEP IDLE: Completely off after 5 minutes of no movement
        currentColor = CRGB::Black;
        leds[0] = currentColor;
    }
    else if (now - lastMoveTime >= 5000) {
        // IDLE: Direct 16-bit white breathing (no nblend, maximum smoothness)
        uint16_t breath16 = beatsin16(15, 0, 65535); // 0 ensures it fades to completely black
        uint8_t breath = breath16 >> 8;
        currentColor = CRGB(breath, breath, breath);
        leds[0] = currentColor;
    }
    else {
        // TRANSITION: Gentle fade to dim white
        targetColor = CRGB(30, 30, 40);
        nblend(currentColor, targetColor, 8);
        leds[0] = currentColor;
    }
    
    // Apply global brightness (preserves temporal dithering at low levels)
    FastLED.setBrightness(led_brightness);
    FastLED.show();
}

void printHelp() {
    Serial.println();
    Serial.println("╔══════════════════════════════════════════════════════╗");
    Serial.println("║       SMART FILAMENT SENSOR - HELP MENU v" FW_VERSION "     ║");
    Serial.println("╠══════════════════════════════════════════════════════╣");
    Serial.println("║  COMMANDS:                                          ║");
    Serial.println("║  ─────────────────────────────────────────────────  ║");
    Serial.println("║  HELP / ?        Show this help menu                ║");
    Serial.println("║  STATUS          Show current settings & state      ║");
    Serial.println("║  START [mm]      Start calibration (default 10mm)   ║");
    Serial.println("║  MEASURE         Start distance measurement         ║");
    Serial.println("║  STOP / END      Stop active mode, go to standby   ║");
    Serial.println("║  VERSION         Show firmware version              ║");
    Serial.println("║  GET_MM          Get odometer mm since last reset     ║");
    Serial.println("║  GET_MM_RESET    Get mm and atomically reset counter  ║");
    Serial.println("║  RESET_MM        Reset odometer counter               ║");
    Serial.println("║  HEALTH          Report magnet health (ok/weak/strong)║");
    Serial.println("║  GET_CAL         Report calibration factor (deg/mm)   ║");
    Serial.println("║  GET_STEPS       Report raw encoder steps             ║");
    Serial.println("║  DIAG            Dump AS5600 registers (diagnostics)  ║");
    Serial.println("║                                                     ║");
    Serial.println("║  SETTINGS:                                          ║");
    Serial.println("║  ─────────────────────────────────────────────────  ║");
    Serial.println("║  SET SENS <1-50>     Runout detection sensitivity   ║");
    Serial.println("║  SET NOISE <1-20>    Noise filter threshold (steps) ║");
    Serial.println("║  SET DIR <1/-1>      Encoder direction multiplier   ║");
    Serial.println("║  SET BRIGHT <1-255>  LED brightness                 ║");
    Serial.println("║  SET CAL <float>     Calibration factor (deg/mm)    ║");
    Serial.println("║  RESET               Reset all settings to default  ║");
    Serial.println("╠══════════════════════════════════════════════════════╣");
    Serial.println("║  CURRENT SETTINGS:                                  ║");
    Serial.println("║  ─────────────────────────────────────────────────  ║");
    Serial.printf( "║  Calibration : %.4f deg/mm                   ║\n", degrees_per_mm);
    Serial.printf( "║  Sensitivity : %-3d (min steps to register movement) ║\n", sensitivity);
    Serial.printf( "║  Noise Filter: %-3d (deadband, encoder steps)       ║\n", noise_threshold);
    Serial.printf( "║  Direction   : %-2d                                  ║\n", direction_multiplier);
    Serial.printf( "║  Brightness  : %-3d / 255                           ║\n", led_brightness);
    Serial.printf( "║  Timeout     : %lu ms                            ║\n", TIMEOUT_MS);
    Serial.println("║                                                     ║");
    Serial.println("║  LED STATES:                                        ║");
    Serial.println("║  ─────────────────────────────────────────────────  ║");
    Serial.println("║  White Breathing = Idle (5s+ no movement)           ║");
    Serial.println("║  LED Off         = Deep Idle (5m+ no movement)      ║");
    Serial.println("║  Blue Pulsing    = Filament moving                  ║");
    Serial.println("║  Solid Green     = Measure mode                     ║");
    Serial.println("║  Solid Yellow    = Calibration mode                 ║");
    Serial.println("╚══════════════════════════════════════════════════════╝");
    Serial.println();
}

void printStatus() {
    Serial.println("\n┌─── STATUS ────────────────────────────┐");
    Serial.printf( "│ Mode : %-12s  Magnet: %-9s │\n",
                   test_active ? "CALIBRATION" : (measure_active ? "MEASURE" : "STANDBY"),
                   as5600.detectMagnet() ? "OK" : "NO MAGNET");
    Serial.printf( "│ CAL:%.4f  SENS:%d  NOISE:%d  DIR:%d  │\n", 
                   degrees_per_mm, sensitivity, noise_threshold, direction_multiplier);
    Serial.printf( "│ BRIGHT:%-3d                                    │\n",
                   led_brightness);
    Serial.printf( "│ AGC:%d  Steps:%lld                         │\n", 
                   as5600.readAGC(), global_steps);
    Serial.println("└───────────────────────────────────────┘");
}

// ═══════════════════════════════════════════════════
//  SETUP
// ═══════════════════════════════════════════════════
void setup() {
    Serial.begin(115200);
    delay(500);
    Wire.begin(SDA_PIN, SCL_PIN);
    Wire.setClock(400000); 
    as5600.begin();
    
    // AS5600 Configuration for maximum responsiveness.
    //
    // setSlowFilter takes the raw SF bit pattern, NOT a "level". Per the
    // AS5600 datasheet CONF[1:0]: 0 = 16x, 1 = 8x, 2 = 4x, 3 = 2x. Passing 0
    // therefore selected the SLOWEST, most heavily filtered mode -- the exact
    // opposite of the old comment. 3 = 2x is the minimum filtering.
    as5600.setWatchDog(0);     // Always-on mode (no low-power sleep)
    as5600.setSlowFilter(3);   // 2x = minimum slow filtering
    as5600.setFastFilter(0);   // 0 = slow filter only (fast filter disabled)
    as5600.setHysteresis(0);   // No hardware hysteresis (handled in software)
    
    // FastLED setup
    FastLED.addLeds<WS2812B, NEO_PIN, GRB>(leds, NUM_LEDS);
    FastLED.setCorrection(TypicalSMD5050);
    FastLED.setDither(BINARY_DITHER);      // Temporal dithering for extra smoothness
    FastLED.setMaxPowerInMilliWatts(500);   // Power safety limit
    
    prefs.begin("sensor", false);
    degrees_per_mm    = prefs.getFloat("cal", 12.5);
    sensitivity       = prefs.getInt("sens", 5);
    noise_threshold   = prefs.getInt("noise", 3);
    direction_multiplier = prefs.getInt("dir", 1);
    led_brightness    = prefs.getInt("bright", 50);

    leds[0] = CRGB(50, 50, 50);
    FastLED.show();
    
    // Warmup: read a few times to stabilize
    for (int i = 0; i < 5; i++) {
        as5600.rawAngle();
        delay(2);
    }
    lastAngle = as5600.rawAngle();
    lastMoveTime = millis();
    lastMoveLedTime = 0; // Start in idle mode
    
    // Magnet check on boot
    Serial.printf("\n>>> SMART FILAMENT SENSOR v%s\n", FW_VERSION);
    if (!as5600.detectMagnet()) {
        Serial.println(">>> WARNING: No magnet detected! Check sensor positioning.");
    } else {
        uint8_t agc = as5600.readAGC();
        // At 3.3V the AGC range is 0-128 and the ideal value is the middle
        // of it (~64). Both extremes hurt accuracy, so report both.
        if (as5600.magnetTooWeak()) {
            Serial.printf(">>> WARNING: Magnet too weak (AGC %d)! Move it closer.\n", agc);
        } else if (as5600.magnetTooStrong()) {
            Serial.printf(">>> WARNING: Magnet too strong (AGC %d)! Increase the air gap.\n", agc);
        } else {
            Serial.printf(">>> Magnet OK (AGC: %d, ideal ~64 at 3.3V)\n", agc);
        }
    }
    Serial.println(">>> Type 'HELP' or '?' for commands.\n");
}

// ═══════════════════════════════════════════════════
//  MAIN LOOP
// ═══════════════════════════════════════════════════
void loop() {
    // ── 1. Command Parser ──
    if (Serial.available()) {
        String input = Serial.readStringUntil('\n');
        input.trim();

        if (input.length() > 0) {
        String upperInput = input;
        upperInput.toUpperCase();

        if (upperInput == "HELP" || upperInput == "?") {
            printHelp();
        }
        else if (upperInput == "VERSION") {
            Serial.printf(">>> Smart Filament Sensor v%s\n", FW_VERSION);
        }
        else if (upperInput == "PING") {
            Serial.println("PONG");
        }
        else if (upperInput == "GET_MM") {
            double measured = calculateDistance(global_steps - odometer_reset_steps);
            Serial.printf("MM:%.4f\n", measured);
        }
        else if (upperInput == "RESET_MM") {
            odometer_reset_steps = global_steps;
            Serial.println("MM:RESET");
        }
        else if (upperInput == "GET_MM_RESET") {
            double measured = calculateDistance(global_steps - odometer_reset_steps);
            odometer_reset_steps = global_steps;
            Serial.printf("MM:%.4f\n", measured);
        }
        else if (upperInput == "GET_CAL") {
            // Machine-readable calibration factor. Klipper needs this to tell
            // "the encoder is slipping" apart from "the stored deg/mm is
            // wrong" -- previously the value was only visible in the human
            // STATUS block, which the Klipper module does not parse.
            Serial.printf("CAL:%.4f\n", degrees_per_mm);
        }
        else if (upperInput == "DIAG") {
            // Full AS5600 register dump on one machine-readable line.
            // ZPOS/MPOS/MANG non-default => readAngle() would have been
            // scaled; CONF holds the filter/hysteresis/watchdog bits; ZMCO
            // counts how many times the chip has been permanently burned.
            Serial.printf(
                "DIAG:fw=%s,cal=%.4f,dir=%d,noise=%d,sens=%d,"
                "zmco=%u,zpos=%u,mpos=%u,mang=%u,conf=0x%04X,"
                "agc=%u,mag=%u,magnet=%u,steps=%lld\n",
                FW_VERSION, degrees_per_mm, direction_multiplier,
                noise_threshold, sensitivity,
                (unsigned)as5600.getZMCO(), (unsigned)as5600.getZPosition(),
                (unsigned)as5600.getMPosition(), (unsigned)as5600.getMaxAngle(),
                (unsigned)as5600.getConfiguration(),
                (unsigned)as5600.readAGC(), (unsigned)as5600.readMagnitude(),
                (unsigned)(as5600.detectMagnet() ? 1 : 0), global_steps);
        }
        else if (upperInput == "GET_STEPS") {
            // Raw encoder steps since the last odometer reset. Lets the host
            // recompute mm with any deg/mm without reflashing.
            Serial.printf("STEPS:%lld\n", global_steps - odometer_reset_steps);
        }
        else if (upperInput == "HEALTH") {
            // Report magnet health for Klipper monitoring.
            //
            // The old code tested `agc > 240` for "too weak". That test can
            // never fire on this board: the AS5600 AGC range is 0-255 at 5V
            // but only 0-128 at 3.3V, and the ESP32-C3 runs the sensor at
            // 3.3V. So the weak-magnet warning was dead code, and there was
            // no strong-magnet warning at all -- an AGC pinned at 0 (magnet
            // far too close) reported "ok".
            //
            // Use the chip's own MH / ML status bits instead of guessing
            // from AGC. Per the datasheet the ideal AGC sits in the MIDDLE
            // of its range, so ~64 at 3.3V; adjust the air gap to get there.
            bool detected = as5600.detectMagnet();
            uint8_t agc = as5600.readAGC();
            if (!detected) {
                Serial.println("HEALTH:no_magnet");
            } else if (as5600.magnetTooWeak()) {
                Serial.printf("HEALTH:too_weak:%d\n", agc);
            } else if (as5600.magnetTooStrong()) {
                Serial.printf("HEALTH:too_strong:%d\n", agc);
            } else {
                Serial.printf("HEALTH:ok:%d\n", agc);
            }
        }
        else if (upperInput == "APPLY") {
            if (test_active) {
                test_active = false;
                long long test_steps = global_steps - session_start_steps;
                float measured_mm = fabs(calculateDistance(test_steps));
                if (llabs(test_steps) > 10) { 
                    float correction = test_target / measured_mm;
                    if (correction > 0.33 && correction < 3.0) {
                        degrees_per_mm = degrees_per_mm / correction;
                        prefs.putFloat("cal", degrees_per_mm); 
                        Serial.printf("\n>>> CALIBRATION SUCCESS!\n");
                        Serial.printf(">>> Measured: %.2f mm | Target: %.1f mm\n", measured_mm, test_target);
                        Serial.printf(">>> New Cal Factor: %.4f deg/mm (saved)\n", degrees_per_mm);
                Serial.printf("CAL:%.4f\n", degrees_per_mm);
                    } else {
                        Serial.println("\n>>> ERROR: Calibration result too far off. Try again.");
                        Serial.printf(">>> Measured: %.2f mm | Target: %.1f mm | Correction: %.2fx\n", measured_mm, test_target, correction);
                    }
                } else {
                    Serial.println("\n>>> ERROR: No significant movement detected, calibration cancelled.");
                }
            } else {
                Serial.println(">>> ERROR: Calibration not active.");
            }
        }
        else if (upperInput.startsWith("SET SENS ")) {
            int val = upperInput.substring(9).toInt();
            if (val >= 1 && val <= 50) {
                sensitivity = val;
                prefs.putInt("sens", sensitivity);
                Serial.printf(">>> Sensitivity set to %d (saved)\n", sensitivity);
            } else {
                Serial.println(">>> ERROR: Sensitivity must be 1-50");
            }
        }
        else if (upperInput.startsWith("SET DIR ")) {
            int val = upperInput.substring(8).toInt();
            if (val == 1 || val == -1) {
                direction_multiplier = val;
                prefs.putInt("dir", direction_multiplier);
                Serial.printf(">>> Direction set to %d (saved)\n", direction_multiplier);
            } else {
                Serial.println(">>> ERROR: Direction must be 1 or -1");
            }
        }
        else if (upperInput.startsWith("SET BRIGHT ")) {
            int val = upperInput.substring(11).toInt();
            if (val >= 1 && val <= 255) {
                led_brightness = val;
                prefs.putInt("bright", led_brightness);
                Serial.printf(">>> Brightness set to %d (saved)\n", led_brightness);
            } else {
                Serial.println(">>> ERROR: Brightness must be 1-255");
            }
        }
        else if (upperInput.startsWith("SET NOISE ")) {
            int val = upperInput.substring(10).toInt();
            if (val >= 1 && val <= 20) {
                noise_threshold = val;
                prefs.putInt("noise", noise_threshold);
                Serial.printf(">>> Noise threshold set to %d steps (saved)\n", noise_threshold);
            } else {
                Serial.println(">>> ERROR: Noise threshold must be 1-20");
            }
        }
        else if (upperInput.startsWith("SET CAL ")) {
            float val = input.substring(8).toFloat();
            if (val > 0.01 && val < 1000.0) {
                degrees_per_mm = val;
                prefs.putFloat("cal", degrees_per_mm);
                Serial.printf(">>> Calibration factor set to %.4f deg/mm (saved)\n", degrees_per_mm);
                Serial.printf("CAL:%.4f\n", degrees_per_mm);
            } else {
                Serial.println(">>> ERROR: Cal factor must be between 0.01 and 1000.0");
            }
        }
        else if (upperInput == "RESET") {
            degrees_per_mm = 12.5;
            sensitivity = 5;
            noise_threshold = 3;
            direction_multiplier = 1;
            led_brightness = 50;
            prefs.putFloat("cal", degrees_per_mm);
            prefs.putInt("sens", sensitivity);
            prefs.putInt("noise", noise_threshold);
            prefs.putInt("dir", direction_multiplier);
            prefs.putInt("bright", led_brightness);
            Serial.println(">>> All settings reset to defaults (saved)");
            printHelp();
        }
        else if (upperInput.startsWith("START")) {
            int spaceIndex = input.indexOf(' ');
            test_target = (spaceIndex != -1) ? input.substring(spaceIndex + 1).toFloat() : 10.0;
            if (test_target < 1.0 || test_target > 500.0) {
                Serial.println(">>> ERROR: Target must be 1-500 mm");
            } else {
                session_start_steps = global_steps;
                test_active = true; measure_active = false;
                lastLoggedMm = -999.0;
                lastMoveTime = millis();
                Serial.printf(">>> CALIBRATION ACTIVE: Push exactly %.1f mm of filament, then wait.\n", test_target);
            }
        } 
        else if (upperInput == "MEASURE") {
            session_start_steps = global_steps;
            measure_active = true; test_active = false;
            lastLoggedMm = -999.0;
            lastMoveTime = millis();
            Serial.println(">>> MEASURE ACTIVE");
        }
        else if (upperInput == "STATUS") {
            printStatus();
        }
        else if (upperInput == "STOP" || upperInput == "END") {
            if (measure_active) {
                long long rel_steps = global_steps - session_start_steps;
                float final_mm = calculateDistance(rel_steps);
                Serial.printf(">>> MEASURE ENDED: Total = %.2f mm (%lld steps)\n", final_mm, rel_steps);
            }
            measure_active = false; test_active = false;
            Serial.println(">>> STANDBY");
        }
        else {
            Serial.println(">>> Unknown command. Type 'HELP' or '?' for available commands.");
        }
        } // end if (input.length() > 0)
    }

    // ── 2. Encoder Reading ──
    //
    // rawAngle(), NOT readAngle(). readAngle() returns the ANGLE register,
    // which the chip scales and clamps according to ZPOS / MPOS / MANG. If
    // those registers hold anything other than defaults, part of every
    // revolution saturates at 0 or 4095 and those encoder steps are lost for
    // good -- a constant multiplicative under-read that looks exactly like a
    // partial clog and that calibration cannot reliably compensate (the loss
    // depends on where in the revolution you start). rawAngle() is the
    // unprocessed 12-bit reading and is immune to all of it. Run DIAG to see
    // what those registers actually contain.
    uint16_t currentAngle = as5600.rawAngle();
    int rawDelta = (int)currentAngle - (int)lastAngle;
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

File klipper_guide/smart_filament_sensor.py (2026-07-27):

# smart_filament_sensor.py — Klipper klippy extra module
#
# ═══════════════════════════════════════════════════════════════════════════
#  SMART FILAMENT SENSOR — Klipper Native Module
#  Version: see __version__ below (reported by SFS_STATUS)
# ═══════════════════════════════════════════════════════════════════════════
#
#  ESP32 is a pure measurement device. It only reports how many mm of
#  filament the encoder measured. All clog detection logic lives here.
#
# ─── WHY THE DETECTION WINDOW IS MEASURED IN mm, NOT SECONDS ──────────────
#
#   This sensor is frame-mounted and connected to the toolhead by a bowden
#   tube (PC4-M6 fittings). The filament between the sensor and the extruder
#   is therefore NOT rigidly coupled: as the toolhead moves, the path length
#   changes and the filament is dragged back and forth through the encoder.
#   Buckling inside the tube stores and releases even more length.
#
#   Measured on real prints (klippy logs, July 2026): individual detection
#   windows read anywhere from -13.8mm to +17.2mm while the commanded
#   extrusion was ~7mm and the configured retraction was only 0.8mm. This
#   drag is bounded and averages to zero over distance, but over a handful of
#   windows it looks exactly like a clog.
#
#   The old detector averaged over `underextrusion_period` SECONDS. Window
#   spacing on a real print is ~2s median, so a 5s average contained a median
#   of THREE samples — and 9% of the time a single one. A pause was therefore
#   decided on 2-3 readings. In the log that triggered a false clog, the
#   deciding average was literally two windows: expected=15.62 actual=-9.07.
#
#   Averaging over EXTRUDED DISTANCE fixes this at the root. Drag amplitude
#   is bounded in mm, so its relative contribution shrinks as the window
#   grows, while a real clog reads ~100% deficit at every window size.
#   Replaying the same logs with perfect calibration, the worst drag-only
#   excursion was:
#
#        window    worst false underextrusion
#         25 mm            260 %
#         50 mm            106 %
#        100 mm             88 %
#        150 mm             58 %
#        200 mm             41 %
#        300 mm             26 %
#
#   At 200mm the 50% threshold has real margin, and a total clog is still
#   caught after ~115mm of commanded extrusion (~25s at typical flow).
#
# ─── CALIBRATION MATTERS MORE THAN IT USED TO ─────────────────────────────
#
#   A distance-averaged detector integrates a steady calibration error
#   instead of hiding it. Both analysed logs showed the encoder reading only
#   61-63% of the commanded extrusion — a permanent 37-39% "underextrusion"
#   that ate three quarters of the headroom to the trigger threshold.
#
#   This module now measures that ratio continuously and reports it
#   (SFS_STATUS -> encoder_gain). If it is not close to 1.00, detection is
#   NOT armed and the module says so, instead of pausing prints for a
#   calibration problem. Fix it with SFS_AUTO_CALIBRATE, or compensate a
#   known steady bias with `encoder_scale`.
#
# ─── PROTOCOL ─────────────────────────────────────────────────────────────
#
#   Klipper → ESP32:  "GET_MM_RESET\n"   read encoder mm + atomically reset
#   ESP32   → Klipper: "MM:<float>\n"    mm measured since last reset
#
#   Klipper → ESP32:  "GET_MM\n"         read encoder mm (no reset)
#   Klipper → ESP32:  "RESET_MM\n"       reset counter only
#   Klipper → ESP32:  "HEALTH\n"         query magnet health
#   ESP32   → Klipper: "HEALTH:<state>:<agc>\n"
#                                        ok, too_weak, too_strong, no_magnet
#   Klipper → ESP32:  "GET_CAL\n"        query calibration factor  (fw >=2.4)
#   Klipper → ESP32:  "GET_STEPS\n"      raw encoder steps         (fw >=2.4)
#   ESP32   → Klipper: "CAL:<float>\n"   deg/mm currently stored
#   Klipper → ESP32:  "DIAG\n"           dump AS5600 registers     (fw >=2.4)
#   ESP32   → Klipper: "DIAG:<k=v,...>\n"
#
#   Klipper → ESP32:  "START <mm>\n"     start calibration with target mm
#   Klipper → ESP32:  "APPLY\n"          force-save calibration immediately
#   Klipper → ESP32:  "STOP\n"           cancel calibration / measure
#   Klipper → ESP32:  "SET SENS|NOISE|BRIGHT|DIR|CAL <v>\n"
#
# ─── INSTALLATION ─────────────────────────────────────────────────────────
#
#   1. Upload this file via Mainsail/Fluidd (Machine tab)
#   2. SSH:  mv ~/printer_data/config/smart_filament_sensor.py \
#                ~/klipper/klippy/extras/
#      mv, not cp -- a leftover copy in the config folder shows up in the
#      Mainsail/Fluidd file list as if it were a config file, and editing
#      that copy does nothing: Klipper loads the one in klippy/extras/.
#   3. Add the config section below to printer.cfg
#   4. sudo systemctl restart klipper
#
# ─── printer.cfg ──────────────────────────────────────────────────────────
#
#   [smart_filament_sensor sfs]
#   serial: /dev/serial/by-id/usb-Espressif_...   # fixed path recommended
#   baud: 115200
#   detection_length: 7.0          # mm of extrusion per encoder read
#   detection_window: 200.0        # mm of extrusion averaged per decision
#   underextrusion_max_rate: 0.5   # 0.0-1.0 deficit that counts as a clog
#   min_window_samples: 8          # reads required before any decision
#   encoder_scale: 1.0             # multiplies encoder mm (bias correction)
#   gain_tolerance: 0.25           # |gain-1| above this disarms detection
#   pause_on_runout: True
#   runout_gcode: PAUSE
#   health_check_interval: 30.0
#
# ─── GCODE COMMANDS ───────────────────────────────────────────────────────
#
#     SFS_STATUS          Show state, health, encoder gain, window fill
#     SFS_ENABLE          Enable clog detection
#     SFS_DISABLE         Disable clog detection (sensor stays connected)
#     SFS_RESET           Re-sync extruder position and reset ESP32 odometer
#     SFS_DIAG            Dump ESP32 calibration + AS5600 registers
#
#     SFS_AUTO_CALIBRATE [TEMP=240] [LENGTH=50] [SPEED=100]
#     SFS_CALIBRATE [LENGTH=10] / SFS_CALIBRATE_APPLY / SFS_CALIBRATE_STOP
#     SFS_SET SENS= NOISE= BRIGHT= DIR= CAL=
#     SFS_MEASURE         1st call resets, extrude, 2nd call shows measured mm
#     SFS_SUSPEND / SFS_RESUME   Silence the module during probing (nestable)
#
# ═══════════════════════════════════════════════════════════════════════════

import serial
import threading
import logging
import time
import glob
import os

__version__ = "3.1.3"

# Expected PING→PONG identifier for auto-detect (avoids grabbing CAN/EBB ports)
_SFS_IDENTITY = "PONG"
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

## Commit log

2026-05-19 Add STL files and klipper guide
    [BackCover.3mf, MagnetHolder.3mf, SmartFilament_Body_w-out_Text.3mf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]
2026-05-20 v2.2: add underextrusion tracking, magnet health, sensor watchdog, homing awareness
    - Klipper module: get_status() for Moonraker/dashboard integration
    - Klipper module: rolling underextrusion rate (actual/expected ratio)
    - Klipper module: sensor disconnect detection with auto-reconnect
    - Klipper module: magnet health monitoring via HEALTH command
    - Klipper module: homing awareness (pause detection during homing)
    - Klipper module: 250ms polling (was 500ms)
    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
2026-05-23 v2.2.1: fix calibration log flooding (0.01mm -> 1.0mm interval), serial disconnect fixes
    [smart_filament_sensor.ino, smart_filament_sensor.py]
2026-05-23 v2.3: auto-detect serial port, connection guard on commands
    - Serial port auto-detection: set serial: auto in printer.cfg, no more /dev/ttyACM0 changing on restart
    - All GCode commands now check sensor connection before executing
    - Calibration log interval: 0.01mm -> 1.0mm (fixes Klipper console flooding)
    - README simplified and updated
    [smart_filament_sensor.py]
2026-05-23 update README: Mainsail/Fluidd upload workflow for Klipper setup
2026-05-23 v2.5: time-based underextrusion detection, retraction filter fix
    - Replace consecutive clog threshold with Roadrunner-style time-based detection
    - underextrusion_max_rate + underextrusion_period: only pause if sustained
    - Single bad readings never pause the print
    - Fix retraction filter threshold: -0.5mm -> -20mm (normal retractions were triggering reset)
    - Rename pause_on_clog/clog_gcode -> pause_on_runout/runout_gcode
    - Remove tolerance config (replaced by rate-based detection)
    - SFS_STATUS shows underextrusion timer state
    - KLIPPER_GUIDE.txt updated to v2.5
    - README updated with new config and detection flow
    [smart_filament_sensor.py]
2026-05-23 v2.5: add SFS_AUTO_CALIBRATE, git-based install with Moonraker auto-update
    - SFS_AUTO_CALIBRATE: one-command calibration (heat, extrude, save)
    - install.sh: symlink-based install, works with Moonraker update_manager
    - README/KLIPPER_GUIDE updated with git install + moonraker.conf setup
2026-05-23 fix: SFS_AUTO_CALIBRATE default temp 200 -> 240C (safe for all materials)
    [smart_filament_sensor.py]
2026-05-25 install.sh: klipper git exclude eklendi, untracked file uyarisi giderildi
2026-05-25 PING/PONG handshake duzeltildi, Klipper auto-detect calisiyor
2026-07-09 Fix link to Interactive CAD Model in README
    Updated the link for the Interactive CAD Model in the README.
2026-07-10 SFS_MEASURE komutu eklendi - print state gerektirmeden encoder mm olcumu
2026-07-16 fix: USB kopmasinda sahte clog pause'u onle + otomatik reconnect (v2.6.0)
    Sensor USB'de koptugunda/reset attiginda baski sahte "CLOG detected"
    ile duruyordu. ESP32 yeniden basladiginda encoder sayaci sifirlaniyor,
    Klipper ise kendi expected extrusion'ini saymaya devam ediyordu; aradaki
    fark underextrusion olarak okunup pause tetikliyordu. "Veri yok" durumu
    "filament akmiyor" gibi degerlendiriliyordu.
    - Reconnect'te detection state sifirlanir, RESET_MM + E-pos resync yapilir,
    5sn grace boyunca clog karari verilmez
    - Kayip GET_MM_RESET cevabi tespit edilir: sayac ESP32'de zaten sifirlandigi
    icin o pencerenin hareketi kayiptir, eslestirmek yerine resync edilir
    - Baglanti yokken detection c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
    [smart_filament_sensor.py]
2026-07-16 fix: medyan filtresi encoder adimlarini yiyordu, kaldirildi (fw 2.3.0)
    Gercek baskida sensor %80'e varan sahte underextrusion bildiriyordu ve
    clog sanip baskiyi duruyordu. Kalibrasyonda ayni sensor 50mm'yi 49.45mm
    (%98.9) dogru okuyordu.
    Sebep: global_steps'e medyan degeri ekleniyor, ama lastAngle gercek
    currentAngle'a ilerletiliyordu. rawDelta ile medyan arasindaki fark her
    seferinde kalici olarak kayboluyordu.
    hist=[50,10,10] -> medyan=10 -> global += 10, lastAngle = currentAngle
    gercek hareket 50, sayilan 10, kalan 40 silindi
    Sabit hizda rawDelta degismedigi icin medyan == gercek, kayip yok — bu
    yuzden yavas ve tek parca kalibrasyon extrude'u dogru olcuyordu. Baskida
    surekli ivme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
    [smart_filament_sensor.ino]
2026-07-16 fix: port taramasi Klipper MCU portlarina PING yazmasin (v2.6.1)
    Auto-detect butun /dev/ttyACM* ve /dev/ttyUSB* portlarini aciyor ve her
    birine "PING\n" yaziyordu. Bu portlardan biri Octopus'un MCU portu; ayni
    zamanda EBB36'nin CAN koprusu. MCU'nun seri akisina PING girince
    haberlesme bozuluyor:
    MCU 'EBBCan' shutdown: Missed scheduling of next digital out event
    Onceden tarama sadece acilista bir kez calisiyordu. Otomatik reconnect
    eklenince sensor her koptugunda 30sn'de bir tekrarlar hale geldi, yani
    canli baskinin ortasinda MCU'ya PING gidiyordu.
    - _klipper_mcu_ports(): mcu bolumlerindeki serial yollari (realpath dahil)
    toplanir, tarama bunlara asla dokunmaz. Yollar okunamazsa hicbir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
    [smart_filament_sensor.py]
2026-07-16 fix: retraction muhasebesi sahte clog uretiyordu (v2.7.0)
    Gercek baskida clog olmadan "Underextrusion 260.8%" ile pause ediyordu.
    %100'un ustu aritmetik olarak imkansiz (max(0, 1-actual/expected) en fazla
    1.0 verir) - actual'in negatif olmasi gerekir. Yani encoder net negatif
    okuyordu.
    Sebep: retraction expected'dan siliniyor ama encoder'da kaliyordu.
    elif delta < 0:
    self._last_e_pos = current_e # retraction expected'dan silindi
    return # ama RESET_MM gonderilmedi
    Sonraki pencerede encoder -6mm retract + 7mm extrude = +1mm bildiriyor,
    expected ise 7mm. 1/7 = %14 -> %86 sahte underextrusion. Daha once gorulen
    %83.5 tam olarak buydu.
    Firmware'deki med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
    [smart_filament_sensor.py]
2026-07-16 fix: uc kenar durumu daha - timer gap, resume desync, MEASURE cakismasi (v2.7.1)
    Tam kod taramasinda bulunan uc acik:
    1. Clog timer ornek bosluklarini atliyordu. Rate esigi asilinca timer
    basliyor; uzun travel'da yeni ornek gelmeyince timer donuyor ama
    sifirlanmiyordu. Travel sonrasi ILK ornek de kotuyse elapsed cotan
    5sn'yi gecmis oluyordu -> tek okumayla aninda pause. Duzeltme: onceki
    ornekten bu yana underextrusion_period'dan uzun bosluk varsa ornekler
    ve timer sifirlanir.
    2. Pause/resume sonrasi muhasebe kaymasi. Pause'da elle extrude/purge
    (filament degisimi) encoder'da sayiliyor ama expected'a girmiyordu.
    Duzeltme: not-printing -> printing gecisinde iki taraf da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
    [smart_filament_sensor.py]
2026-07-17 fix: modul probe sirasinda reactor'i bloklamasin - EBBCan crash (v2.8.0)
    Print sirasinda z_tilt/mesh probe aninda EBBCan cokuyordu:
    Unable to obtain 'trsync_state' response
    Manuel z_tilt (100x) hic cokmuyor; sadece PRINT sirasinda. Isi degil
    (255/80'de manuel z_tilt temiz). Ard arda test kesinlestirdi:
    sfs_enable -> print z_tilt sonrasi COKME
    SFS_DISABLE -> z_tilt + mesh TEMIZ gecti
    Sebep: modul Klipper'in tek-thread reactor'inda seri I/O + reader thread
    calistiriyor. Probe aninda host trsync'i mikrosaniye penceresinde
    servis etmeli; modulun seri yazmasi / get_position() / reader GIL'i
    reactor'i geciktirince trsync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
    [smart_filament_sensor.py]
2026-07-20 fix: SFS_SUSPEND/SFS_RESUME - rapid_scan mesh korumasiz kaliyordu (v2.9.0)
    v2.8.0'in homing-event tabanli korumasi yetersiz cikti, iki delik:
    1. rapid_scan bed mesh homing hareketi KULLANMIYOR - eddy probe surekli
    akis halinde tararken homing:homing_move_begin/end hic ateslenmiyior.
    Modul mesh boyunca tam aktifti; akisin ortasindaki seri I/O "probe_eddy
    _current sensor outage" + "Missed scheduling" cokmesine yol acti.
    2. homing_override eksenler arasi G4 P1000 bekliyor; 0.75s _probe_grace
    bu boslukta doluyor, guard kalkip RESET_MM gonderebiliyordu.
    Testle dogrulandi: SFS acik -> homing'de ve mesh'te cokme; SFS_DISABLE ->
    ayni print temiz.
    Cozum: acik SFS_SUSPEND / SFS_RESUME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
    [smart_filament_sensor.py]
2026-07-27 feat: distance-based clog detection + self-checking calibration (v3.1.3 / fw 2.5.0)
    Root cause of the false clog detections: the sensor is frame-mounted, the
    extruder is on the toolhead, and there is a bowden tube between them. As the
    toolhead moves, the path length changes and filament is dragged back and forth
    through the encoder. On real print logs a single 7mm window read anywhere from
    -13.8mm to +17.2mm -- with retraction set to only 0.8mm.
    The old detector averaged that noise over SECONDS. Detection windows arrive
    about every 2s on a real print, so a 5-second average held a median of THREE
    samples, and a single sample 9% of the time. The decision that triggered the
    PAUSE was literally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
    [smart_filament_sensor.ino, smart_filament_sensor.py]
